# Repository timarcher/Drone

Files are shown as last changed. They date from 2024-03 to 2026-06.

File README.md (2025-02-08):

# Hexacopter Build Project
Welcome to the Hexacopter Build Project! Follow along as I embark on a journey to create a powerful 1300mm hexacopter from scratch. With a focus on scalability and payload capacity, I'm integrating top-tier components like a carbon fiber frame from RJX Hobby, Hobbywing XRotor X6 motors and a 12s smart battery, alongside exploring the Cube Pilot ecosystem for advanced flight control. I’ll also incorporate a companion computer and some cool cameras and imaging devices to explore things like photogrammetry and thermal imaging. From frame assembly to flight tuning, join me as I document every step of this exciting build, sharing my insights, code, and comprehensive parts list along the way. Let's push the boundaries of drone technology together!

For details [click here to access the wiki and documentation home folder.](./wiki/Drone-Wiki.md)

# Pictures
Hexacopter Pic 1

Hexacopter Pic 2

Hexacopter Pic 3

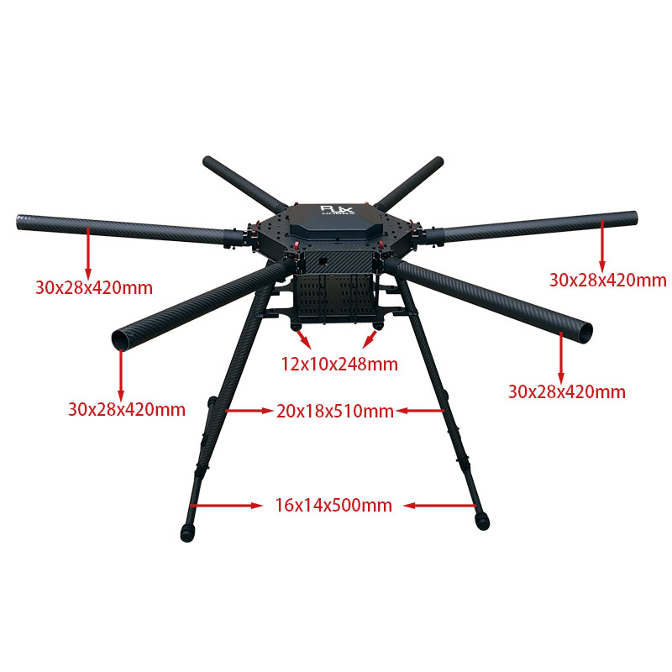
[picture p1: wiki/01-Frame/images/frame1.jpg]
Frame


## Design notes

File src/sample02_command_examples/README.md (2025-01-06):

This directory contains a script showing how to use mavlink to connect to a HereLink and send instructions to the flight controller.
It will attempt to:
- Arm the drone.
- Takeoff to a height of 3 meters.
- Read telemetry for 10 seconds and print to the screen.
- Land the drone.

To setup this script, you must do the following:
1. Make a directory to hold the scripts.
```sh
mkdir ~/drone_scripts
cd ~/drone_scripts
```
1. Copy the files to your linux machine into the diorectry ~/drone_scripts: requirements.txt and log_downloader.py
2. Setup your Python environment.
```sh
sudo apt update
sudo apt install python3-pip

python3 -m venv drone_scripts_env
source drone_scripts_env/bin/activate
pip3 install -r requirements.txt
```
3. Copy the script to your linux machine and execute it:
```sh
python3 sample02_command_examples.py
```

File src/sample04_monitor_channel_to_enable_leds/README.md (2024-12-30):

This directory contains a script to turn on and off the neopixel LEDs through RC Channel 6.
When that channel goes high, the LED scanning pattern will be enabled. When low, it will be turned off.

To setup this script, you must do the following:
1. Make a directory to hold the scripts.
```sh
mkdir ~/drone_scripts
cd ~/drone_scripts
```
2. Copy the files to your linux machine into the diorectry ~/drone_scripts: requirements.txt and monitor_channel_to_enable_leds.py
3. Setup your Python environment.
```sh
sudo apt update
sudo apt install python3-pip

python3 -m venv drone_scripts_env
source drone_scripts_env/bin/activate
pip3 install -r requirements.txt
```
4. Determine the absolute path of the Python interpreter in your environment: 
```sh
which python3
```
5. Create a Systemd Service File to auto start the script:
```sh
sudo vi /etc/systemd/system/led_monitor.service
```

Add the following content, replacing placeholders with actual paths:
```sh
[Unit]
Description=Monitor MAVLink channel and control LED strip
After=network-online.target
Wants=network-online.target

[Service]
Type=simple
User=ubuntu
WorkingDirectory=/home/ubuntu/drone_scripts
#ExecStartPre=/bin/sleep 60
ExecStart=/home/ubuntu/drone_scripts/drone_scripts_env/bin/python3 /home/ubuntu/drone_scripts/monitor_channel_to_enable_leds.py
#Restart=on-failure
Restart=always
TimeoutStartSec=120
Environment="PATH=/home/ubuntu/drone_scripts/drone_scripts_env/bin/python3:/usr/bin:/bin"
StandardOutput=journal
StandardError=journal

[Install]
WantedBy=multi-user.target
```

6. Reload Systemd and Enable the Service
```sh
sudo systemctl daemon-reload
sudo systemctl enable led_monitor.service
```

7. To test the service immediately, run:
```sh
sudo systemctl start led_monitor.service
```

8. Check its status to ensure it’s running:
```sh
sudo systemctl status led_monitor.service
```

9. Reboot and ensure the service is running then after the reboot:
```sh
sudo reboot
sudo systemctl status led_monitor.service
```

10. To debug issues, check the logs:
```sh
journalctl -u led_monitor.service -f
```

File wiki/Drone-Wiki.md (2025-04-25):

Welcome to the Hexacopter Build Project! Follow along as I embark on a journey to create a powerful 1300mm hexacopter from scratch. With a focus on scalability and payload capacity, I'm integrating top-tier components like a carbon fiber frame from RJX Hobby, Hobbywing XRotor X6 motors and a 12s smart battery, alongside exploring the Cube Pilot ecosystem for advanced flight control. I’ll also incorporate a companion computer and some cool cameras and imaging devices to explore things like photogrammetry and thermal imaging. From frame assembly to flight tuning, join me as I document every step of this exciting build, sharing my insights, code, and comprehensive parts list along the way. Let's push the boundaries of drone technology together!

# YouTube Play List
All of the YouTube videos linked in this wiki are organized into a [single playlist](https://www.youtube.com/playlist?list=PLT3XAJfSsN4FFodHkPWbuXHesVJ0ILG6v) you can watch as well. Follow each part of the video playlist in order.

# Preparation
- [Prep Work](Preparation/Preparation.md) - Prior to building and flying your drone, complete this prep work around knowledge, safety, and compliance.

# Bill of Materials
- [Overall BOM](00-Bill-of-Materials/Bill-of-Materials.md) - This page contains the overall bill of materials/component list that was used to construct the drone.

# Step by Step Build Process
Use the list below to follow my build journey step by step.
1. [Frame](01-Frame/Frame.md)
1. [Electronics](02-Electronics-Inventory/Electronics-Inventory.md)
1. [Herelink Unboxing and Configfuration](03-Herelink-Initial-Config/Herelink-Initial-Config.md)
1. [Cube Orange Plus and Kore Carrier Board Unboxing and Configfuration](04-Cube-Orange-Plus-and-Kore-Carrier-Board-Initial-Setup/Cube-Orange-Plus-and-Kore-Carrier-Board-Initial-Setup.md)
1. [Here 4 GPS and Base](05-Here-4-GPS-and-Base/Here-4-GPS-and-Base.md)
1. [Motors](06-Motors/Motors.md)
1. [Onboard OLED Display](07-OLED-Display/OLED-Display.md)
1. [Cube ID Remote ID](08-Cube-ID-Remote-ID/Cube-ID-Remote-ID.md)
1. [Here Flow](09-Here-Flow/Here-Flow.md)
1. [Onboard Computer and Ethernet](10-Onboard-Computer-and-Ethernet/Onboard-Computer-and-Ethernet.md)
1. [TFMini-S Lidar](11-TFMini-S-Lidar/TFMini-S-Lidar.md)
1. [Tattu Smart Battery](12-Tattu-Smart-Battery/Tattu-Smart-Battery.md)
1. [Electronics Installation](13-Electronics-Installation/Electronics-Installation.md)
1. [Navigation Lights](14-Navigation-Lights/Navigation-Lights.md)
1. [Peripheral Updates](15-Peripheral-Updates/Peripheral-Updates.md)
1. [Gimbal and Camera](16-Gimbal-and-Camera/Gimbal-and-Camera.md)
1. [Obstacle Avoidance LiDAR](17-Obstacle-Avoidance-LiDAR/Obstacle-Avoidance-LiDAR.md)
1. [Scanning Lights / Cylon Pattern](18-Scanning-Lights/Scanning-Lights.md)

<!--1. [Methodic Configuration](XX-Methodic-Configuration/Methodic-Configuration.md)-->
<!--1. [ROS Integration](XX-ROS-Integration/ROS-Integration.md)-->

Future steps are coming soon!

# Drone Weight
The weight of this drone is as follows:
- 21.64 lb without battery or payload (just frame, motors, electronics, etc).
- 31.30 lb with battery (The battery is 9.66 lb).
- 27.15 lb with payload and no battery (5.51 lb payload). The payload is the Gremsy T7 Gimbal, Sony A6500 Camera, and supporting electronics.
- 36.85 lb with battery and payload

# Flight Checklist
- [Flight Checklist](Flight-Checklist/Flight-Checklist.md) - This page contains a simple checklist of items to work through before flying.

# Full ArduPilot Configuration Summary
- [ArduPilot Configuration](ArduPilot-Config/ArduPilot-Config.md) - This page contains a consolidated list of the all of the configuration done in ArduPilot throughout the videos.
- However, I would recommend you use the [ArduPilot Methodic Configurator](https://ardupilot.github.io/MethodicConfigurator/TUNING_GUIDE_ArduCopter) with [these config files](../ardupilot-methodic-configurator/Hexacopter/) that I have created. This is how I setup and tuned the drone in its final stages.

# ArduPilot Tools
- [DroneCAN GUI Tool](https://dronecan.github.io/GUI_Tool/Overview/) - a coss-platform free open source application for DroneCAN bus management and diagnostics.
- [Mission Planner](https://ardupilot.org/planner/docs/mission-planner-installation.html) - A GCS allows users to set-up, configure, test, and tune the vehicle. 
- [MavProxy](https://ardupilot.org/mavproxy/) - A UAV ground station software package for MAVLink based systems.

# Flight Training
- [RealFlight Simulator](https://www.realflight.com/) - Awesome flight simulator software you can use to learn to safely fly on your computer.
- [How to Fly a Drone A Beginner's Guide to Multirotor Systems & Flight Proficiency by UAV Coach](https://uavcoach.com/how-to-fly-a-quadcopter-guide/) - Need to learn some of the basics of flying? Start with UAV Coach. The information and videos here will give you basic exercises you can practice to improve your flying skills.

# Other Resources
- [eCalc](https://ecalc.ch/) - Services to simulate, calculate, evaluate and design electric brushless motor drives for RC pilots of airplane, multi rotor, UAV, helicopter and EDF jets.
- [How to methodically configure and tune any ArduCopter Blog Post](https://discuss.ardupilot.org/t/how-to-methodically-configure-and-tune-any-arducopter/110842)
- [Measuring Vibration ArduPilot Article](https://ardupilot.org/copter/docs/common-measuring-vibration.html) - These instructions explain how to measure the vibration levels. If you find they are out-of-tolerance then follow the advice found on the ArduPilot Vibration Damping page.
- [Log Analysis in Mission Planner](https://youtu.be/xhBd9KSAfzg?si=X1SPhqCtfS4Ki4Zp) - A video from Dan Benson offering a complete discussion of log analysis in mission planner. He uses a crash to illustrate how to use the log analysis.

# Pictures
Hexacopter Pic 1

Hexacopter Pic 2

Hexacopter Pic 3

Frame

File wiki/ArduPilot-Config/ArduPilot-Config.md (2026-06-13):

This page contains a consolidated list of the all of the configuration done in ArduPilot throughout the videos. 
Use this to easily setup a new flight controllers.

# Custom Firmware
You will need to build your own custom firmware from [custom.ardupilot.org](http://custom.ardupilot.org/) in order to enable the DID_* parameters for Open Drone ID.
- Press "Add a build"
- For vehicle select Copter
- For branch Select the latest stable branch (i.e., Copter 4.5 stable)
- For board select CubeOrangePlus
- Under the Ident category, check the box for OpenDroneID (Remote ID)
- Press the "Generate Build" button
- Download the generated arducopter.apj file.
- In Mission Planner, go to Setup->Install Firmware
- Press "Load Custom Firmware"
- Select the apj file you downloaded and flash it to the board

# All Firmware and Software Versions
This section lists all the firmware and software versions I am using in this build:
|Component|Version|Link|
|---|---|---|
|ArduCopter|4.6.3|https://custom.ardupilot.org/|
|Gremsy T7 Gimbal|7.8.7|https://github.com/Gremsy/T7-Firmware/releases|
|AirPixel Air Commander Entire R3|2.026|https://airpixel.cz/docs/firmware-update/|
|HereLink QGroundControl|5.0.8-1|https://github.com/CubePilot/qgroundcontrol-herelink/releases|
|MavCam HL|2.24|https://airpixel.cz/docs/herelink-camera-control/|
|Gremsy gTuneDesktop|1.4.9.7|https://github.com/Gremsy/gTuneDesktop/releases|
|AP_Periph MatekL431-Rangefinder|Jun 3 2025|https://firmware.ardupilot.org/AP_Periph/stable/MatekL431-Rangefinder/|
|AP_Periph MatekL431-Proximity|Jun 3 2025|https://firmware.ardupilot.org/AP_Periph/stable/MatekL431-Proximity/|
|Mission Planner|Latest Beta Release|https://ardupilot.org/planner/docs/mission-planner-installation.html|
|ArduPilot Methodic Configurator|Latest Release|https://github.com/ArduPilot/MethodicConfigurator/releases|
|Here4 GPS Firmware|1.15.7|https://github.com/CubePilot/GNSSPeriph-release/releases|
|Tattu TA3200 LiPo Charger Firmware|5/28/2025, v1.4.2|https://www.grepow.com/downloads.html|
|LightWare Studio|1.21.11|https://lightwarelidar.com/resources-software/|
|LightWare SF45 Firmware|External (Motor Controller) 1.3.0 / Internal (LiDAR) 1.1.2|Use LightWare Studio to get latest|

# Initial Setup
After flashing firmware for the first time, use Mission Planner to configure several items:
- Go to Setup tab.
- Expand the Mandatory Hardware menu item.
  - On Frame Type menu item:
    - Select the Hexacopter X pattern.
  - On Initial Tune Parameters menu item:
    - Airscrew Inch Size: 24
    - Battery Cellcount: 12 (or 6 when testing with a 6s battery)
    - Battery cell fully discharged voltage: 3.3
    - Check the option to "Add suggested settings for 4.0 and up (Battery failsafe and Fence)".
    - Press the "Calculate Initial Parameters" button, and then the "Write to FC" button on the popup window.
  - On Accel Calibration menu item:
    - Press Calibrate Accel (use this for when you can manipulate the drone orientation)
    - Press Calibrate Level
    - Press Simple Accel Cal (use this in lieu of Calibrate Accel for large drone or simple bench testing)
    - Docs on accelerometer calibration [can be found here](https://ardupilot.org/copter/docs/common-accelerometer-calibration.html).    
  - On Compass menu item:
    - Swap compasses later to use the external one higher priority than the one on cube once the GPS is installed.
    - Press start on the Onboard Mag Calibration, calibrate, and reboot. Docs on compass calibration [can be found here](https://ardupilot.org/copter/docs/common-compass-calibration-in-mission-planner.html).
  - On Radio Calibration menu item:
    - Prior to calibrating, I had to reverse the joystick outputs in the Herelink controller for the Y (throttle rc2). Otherwise the values were reversed.
    - Press the Calibrate Radio button. Move joysticks and input buttons to their limits. Then press the Click when Done button.
    - Docs on radio calibration [can be found here](https://ardupilot.org/copter/docs/common-radio-control-calibration.html).
    - Be sure to test the controls in Mission Planner. Move the transmitter’s roll, pitch, throttle and yaw sticks and ensure the green bars move in the correct direction:
      - For roll, throttle and yaw channels, the green bars should move in the same direction as the transmitter’s physical sticks.
      - For pitch, the green bar should move in the opposite direction to the transmitter’s physical stick.
      - If one of the green bars moves in the incorrect direction reverse the channel in the transmitter itself. If it is not possible to reverse the channel in the transmitter you may reverse the channel in ArduPilot by checking the “Reversed” checkbox (Plane and Rover only). If the checkbox is not visible it is possible to reverse the channel by directly changing the RCx_REVERSED parameter (where “x” is the input channel from 1 to 4).

# Parameter Settings
To set these parameters in mission planner, navigate to the Config tab, and then the Parameter List menu option.
Note: If you are using a fresh installation of mission planner you will have to enable this page by setting Config->Planner->Layout to “Advanced”

## Parameters - Herelink Telemetry
I changed the default baud rate from 57600 to 115200.
You must also change the baud rate on the air unit. To do this, open the herelink settings, go to Airunit, select 115200 for the baudrate and click Reset Baud.

|Parameter Name|Value|Description|
|---|---|---|
|SERIAL1_BAUD|115|The MAVLink over Herelink telemetry, changed from default of 57600 to 115200.|

## Parameters - Kore carrier board voltage and current sensors
The default params recommended for battery monitoring are on the Kore carrier board page.
However, with the defaults I was getting negative current readings. Per this post I set the BATT_AMP_OFFSET to 0.37. There is also a recommendation to set BATT_AMP_PERVOLT to 67 but I did not do that.
https://discuss.cubepilot.org/t/negative-current-reading-on-kore-carrier-board/2299/11
You do not need to set these if you are going to use the settings below for the Tattu Smart Battery. That battery has a BMS from which ArduPilot can get it's status through DroneCAN.

|Parameter Name|Value|Description|
|---|---|---|
|BATT_MONITOR|4|Set this first, and then write the params so the other ones below show. Must reboot the board after changing. 4 = Analog voltage and current.|
|BATT_AMP_OFFSET|0.37|Kore docs recommend 0.45 but this caused negative current readings on my board.|
|BATT_AMP_PERVLT|50||
|BATT_ARM_VOLT|44.3|Minimum battery voltage required to arm the aircraft.|
|BATT_CAPACITY|15800|The Tattu 12s battery has 16000 mah.|
|BATT_CRT_VOLT|42|Battery voltage that triggers a critical battery failsafe.|
|BATT_CURR_PIN|15|Kore docs recommend 3, but I had to set to 15 to work with Cube Orange Plus.|
|BATT_FS_CRT_ACT|1|Action to perform if the critical battery failsafe is hit. 1 = Land|
|BATT_FS_LOW_ACT|2|Action to perform if the low battery failsafe is hit. 2 = RTL|
|BATT_LOW_VOLT|43.2|Battery voltage that triggers a low battery failsafe.|
|BATT_SERIAL_NUM|-1|Leave at -1.|
|BATT_VOLT_MULT|15.2||
|BATT_VOLT_PIN|14|Kore docs recommend 2, but I had to set to 14 to work with Cube Orange Plus.|

> If you are using the Tattu Smart Battery outlined below, you should skip setting these BATT_* parameters for the Kore Carrier Board. If you wish, you may set the Tattu smart battery settings as described below under BATT_, and then set these values under BATT2_ instead of BATT_ to have a secondary battery monitor using the circuity on the Kore carrier board. If you do that, I recommend you set BATT2_MONITOR to a value of 3, monitoring the analog voltage only. The remaining capacity is more accurately measured through the smart battery, and so also trying to measure current through the Kore carrier board will show a remaining capacity on the 2nd battery monitor that is wrong because it resets between flight controller reboots.

## Parameters - Enable DroneCAN (Needed for Basically everything below)
|Parameter Name|Value|Description|
|---|---|---|
|CAN_P1_DRIVER|1|1st Driver.|
|CAN_P2_DRIVER|2|2nd Driver.|
|CAN_D1_PROTOCOL|1|DroneCAN.|
|CAN_D2_PROTOCOL|1|DroneCAN.|

## Parameters - Here4 GPS
|Parameter Name|Value|Description|
|---|---|---|
|BRD_SAFETY_DEFLT|0|There is no safety switch on the Here4 GPS so we disable it. (BRD_SAFETYENABLE in older firmware versions)|
|GPS1_TYPE|9|GPS type of 1st GPS.|
|NTF_LED_TYPES|231|Controls what types of LEDs will be enabled.|
|GPS_AUTO_CONFIG|2|Needed to enable RTK autocorrect, set to enable for DroneCAN as well.|

If using multiple GPS', as in my drone, also need to set additional params. In my drone, GPS1 (Node 119) is the GPS on the right middle arm of the vehicle, and GPS2 (Node 118) is the GPS on the left middle arm of the vehicle.
|Parameter Name|Value|Description|
|---|---|---|
|GPS1_CAN_OVRIDE|119|Node ID for the 1st GPS. Set appropriately for your vehicle as the Node IDs might be different.|
|GPS2_TYPE|9|GPS type of 2nd GPS.|
|GPS2_CAN_OVRIDE|118|Node ID for the 1st GPS. Set appropriately for your vehicle as the Node IDs might be different.|
|GPS_AUTO_SWITCH|1|Set to Use Best.|

Additionally, you may wish to set the offsets of the sensors relative to the center of your Cube Orange.  Customize the value by measuring the offset from the center of your Cube Orange to the middle of the sensor.
|Parameter Name|Value|Description|
|---|---|---|
|GPS1_POS_X|0.07|X position of the second GPS antenna in body frame. Positive X is forward of the origin. Units in meters.|
|GPS1_POS_Y|0.2413|Y position of the second GPS antenna in body frame. Positive Y is to the right of the origin. Units in meters.|
|GPS1_POS_Z|0.01|Z position of the second GPS antenna in body frame. Positive Z is down from the origin. Units in meters.|
|GPS1_GNSS_MODE|5|Constellations to be used. 0=Set to allow all. 65=GPS and Galileo|
|GPS2_POS_X|0.07|X position of the first GPS antenna in body frame. Positive X is forward of the origin. Units in meters.|
|GPS2_POS_Y|-0.2413|Y position of the first GPS antenna in body frame. Positive Y is to the right of the origin. Units in meters.|
|GPS2_POS_Z|0.01|Z position of the first GPS antenna in body frame. Positive Z is down from the origin. Units in meters.|
|GPS2_GNSS_MODE|5|Constellations to be used. 0=Set to allow all. 65=GPS and Galileo|

New RTK can be used to estimate yaw, in addition to providing position information. This removes the need for a compass which may suffer from magnetic interference from the ground or the vehicle’s motors and ESCs. Set the following to use this as well:
|Parameter Name|Value|Description|
|---|---|---|
|EK3_SRC1_YAW|3|GPS with compass fallback|
|GPS1_TYPE|22|DroneCAN moving baseline base|
|GPS2_TYPE|23|DroneCAN moving baseline rover|
|GPS_AUTO_CONFIG|2|Autoconfig DroneCAN|
|GPS_AUTO_SWITCH|1|Use Best|

> Be sure you set the GPS1_POS_X/Y/Z and GPS2_POS_X/Y/Z parameters for the GPS antennas (see Sensor Position Offset are here) as described above. You must establish the relative positions of each GPS location on the vehicle with respect the vehicle’s motion.

<!--
|XXX|XXX|XXX|
-->

## Parameters - Onboard OLED Display
|Parameter Name|Value|Description|
|---|---|---|
|NTF_DISPLAY_TYPE|1|SSD1306 OLED Connected to I2C.|

## Parameters - Motors
|Parameter Name|Value|Description|
|---|---|---|
|CAN_D1_UC_ESC_BM|63|Bitmask that determines which autopilot servo/motor output signals are sent to the DroneCAN ESCs. 63 = ESC 1 through 6.|
|CAN_D1_UC_OPTION|128|Set options for the DroneCAN driver for Hobbywing ESC.|

## Parameters - Cube ID
Be sure to build and load the custom firmware as described above. Otherwise, you will not see any of the DID_* parameters.
|Parameter Name|Value|Description|
|---|---|---|
|DID_ENABLE|1|Enable Open Drone ID|
|DID_CANDRIVER|1|DroneCAN driver index, 0 to disable DroneCAN.|
|DID_OPTIONS|6|6 sets AllowNonGPSPosition and LockUASIDOnFirstBasicIDRx. First setup the above two params, setup your Drone ID info in mission planner, verify it shows in Drone Scanner, and then set this bit. After your DID_UAS_ID is persisted, the LockUASIDOnFirstBasicIDRx will be unchecked in the params and this value set back to a 2.|

You can optionally set the DID_OPTIONS bitmask value as well for EnforceArming, AllowNonGPSPosition, and LockUASIDOnFirstBasicIDRx.
- EnforceArming = set to enforce arming checks
- AllowNonGPSPosition = allow drone to be armed without a GPS position. If you want to be able to arm without the operator location set this bit. Useful when testing flight controller indoors and not actually flying. You'll hear your Herelink repeat the error "ODID Lost Operator Location" which can get annoying after awhile.
- LockUASIDOnFirstBasicIDRx = To meet FAA requirements for manufacturers, a persistent ID needs to be recorded in Flight system. To achieve this with CubeID + Ardupilot setup. Ardupilot's persistent storage feature is used. After the setting, the first reception of Basic ID containing Drone ID and other details (from Mission Planner or any other GCS) will be persistently recorded. Please note that once set the persistent parameters can't be rolled back. Once the UAS ID is persisted, this will be unchecked and the values stored in the persistent.parm file on the flight controller. It will persist DID_UAS_ID, DID_UAS_ID_TYPE, and DID_UA_TYPE.

## Parameters - Here Flow
|Parameter Name|Value|Description|
|---|---|---|
|RNGFND1_TYPE|24|Type of connected rangefinder. Reboot flight controller after setting this for rest of the params to show.|
|RNGFND1_MIN_CM|10|Minimum distance in centimeters that rangefinder can reliably read.|
|RNGFND1_MAX_CM|200|Maximum distance in centimeters that rangefinder can reliably read.|
|RNGFND1_GNDCLEAR|29|Optional - This parameter sets  the expected range measurement(in cm) that the range finder should return when the vehicle is on the ground.|
|FLOW_TYPE|6|Enable optical flow camera.|

Additionally, you may wish to set the offsets of the sensors relative to the center of your Cube Orange.  Customize the value by measuring the offset from the center of your Cube Orange to the middle of the sensor.
|Parameter Name|Value|Description|
|---|---|---|
|FLOW_POS_X|-0.140|X position of the optical flow sensor focal point in body frame. Positive X is forward of the origin. Units in meters.|
|FLOW_POS_Y|-0.075|Y position of the optical flow sensor focal point in body frame. Positive Y is to the right of the origin. Units in meters.|
|FLOW_POS_Z|0.206|Z position of the optical flow sensor focal point in body frame. Positive Z is down from the origin. Units in meters.|

## Parameters - TFMini-S LiDAR
|Parameter Name|Value|Description|
|---|---|---|
|SERIAL4_PROTOCOL|9|What protocol Serial4 port should be used for. Change from -1 (GPS) to 9 (Lidar)|
|SERIAL4_BAUD|115|The baud rate used for Serial4. 115200 baud.|
|RNGFND2_TYPE|20|Type of connected rangefinder. 20=Benewake-Serial. Reboot flight controller after setting this for rest of the params to show.|
|RNGFND2_MIN_CM|10|Minimum distance in centimeters that rangefinder can reliably read. 10 for TFminiPlus|
|RNGFND2_MAX_CM|600|This is the distance in centimeters that the rangefinder can reliably read. 600 for outdoors.|
|RNGFND2_GNDCLEAR|29|Optional - This parameter sets  the expected range measurement(in cm) that the range finder should return when the vehicle is on the ground.|

If using the Matek AP_PERIPH CAN Node L431 Board to convert your TFMini-S to a DroneCAN device, then set these instead:
|Parameter Name|Value|Description|
|---|---|---|
|RNGFND2_TYPE|24|Type of connected rangefinder. 24=DroneCAN. Reboot flight controller after setting this for rest of the params to show.|
|RNGFND2_MIN_CM|10|Minimum distance in centimeters that rangefinder can reliably read. 10 for TFminiPlus|
|RNGFND2_MAX_CM|600|This is the distance in centimeters that the rangefinder can reliably read. 600 for outdoors.|
|RNGFND2_GNDCLEAR|45|Optional - This parameter sets  the expected range measurement(in cm) that the range finder should return when the vehicle is on the ground.|

Additionally, you may wish to set the offsets of the sensors relative to the center of your Cube Orange.  Customize the value by measuring the offset from the center of your Cube Orange to the middle of the sensor.
|Parameter Name|Value|Description|
|---|---|---|
|RNGFND1_POS_X|-0.160|X position of the rangefinder in body frame. Positive X is forward of the origin. Units in meters.|
|RNGFND1_POS_Y|0|Y position of the rangefinder in body frame. Positive Y is to the right of the origin. Units in meters.|
|RNGFND1_POS_Z|0.211|Z position of the rangefinder in body frame. Positive Z is down from the origin. Units in meters.|

## Parameters - Tattu 12s 16000mAh Smart Battery
These are the settings I used for the Tattu Plus 1.0 Compact Version 16000mAh 44.4V 15C 12S1P Lipo Smart Battery Pack With AS150U Plug.
|Parameter Name|Value|Description|
|---|---|---|
|BATT_MONITOR|8|DroneCAN|
|BATT_AMP_OFFSET|0|This may not show up once you set BATT_MONITOR to 8. Thats OK.|
|BATT_AMP_PERVLT|1|This may not show up once you set BATT_MONITOR to 8. Thats OK.|
|BATT_ARM_VOLT|44.3|Minimum battery voltage required to arm the aircraft.|
|BATT_CAPACITY|15800|The Tattu 12s battery has 16000 mah.|
|BATT_CRT_VOLT|42|Battery voltage that triggers a critical battery failsafe.|
|BATT_CURR_MULT|-1|Multiplier applied to all current related reports. Needed otherwise you get negative current readings from the Tattu battery.|
|BATT_FS_CRT_ACT|1|Action to perform if the critical battery failsafe is hit. 1 = Land|
|BATT_FS_LOW_ACT|2|Action to perform if the low battery failsafe is hit. 2 = RTL|
|BATT_LOW_VOLT|43.2|Battery voltage that triggers a low battery failsafe.|
|BATT_SERIAL_NUM|-1|Leave at -1 unless you have multiple DroneCAN batteries in the drone.|
|MOT_BAT_VOLT_MAX|50.4|Battery voltage compensation maximum voltage. Set to 4.2 * cell count.|
|MOT_BAT_VOLT_MIN|39.6|Battery voltage minimum compensation voltage. Set to 3.3 * cell count.|

## Parameters - Flytron STROBON Cree V2 Lights
|Parameter Name|Value|Description|
|---|---|---|
|SERVO9_FUNCTION|56|Configure for RC Pass thru. 56 = RCIN6 which means RC channel 6 gets output to SERVO9.|

> On the Kore carrier board SERVO9 - SERVO15 are mapped to the 6 auxiliary outputs.
> For testing, on the Herelink controller, go to the settings and map a button to a channel. In my testing I mapped a short press of the D button to RC channel 6, and it toggles between a value of 1000 and 2000 when pressed. And then in Ardupilot, I set SERVO9_FUNCTION to 56, which means to pass RC channel 6 (RCIN6) through to SERVO9. SERVO9 corresponds to the first auxiliary output on the Kore carrier board.

## Parameters - Flight Modes
I have my flight modes configured as follows. This requires some config in ArduPilot as well as the HereLink controller. You can also set these up in Mission Planner on the Setup->Flight Modes screen.

|Parameter Name|Value|Description|
|---|---|---|
|FLTMODE_CH|5|RC Channel to use for flight mode control. Default is 5.|
|FLTMODE1|5|Flight mode when pwm of Flightmode channel(FLTMODE_CH) is <= 1230. Set to Loiter.|
|FLTMODE2|15|Flight mode when pwm of Flightmode channel(FLTMODE_CH) is >1230, <= 1360. Set to AutoTune.|
|FLTMODE3|2|Flight mode when pwm of Flightmode channel(FLTMODE_CH) is >1360, <= 1490. Set to AltHold.|
|FLTMODE4|3|Flight mode when pwm of Flightmode channel(FLTMODE_CH) is >1490, <= 1620. Set to Auto.|
|FLTMODE5|6|Flight mode when pwm of Flightmode channel(FLTMODE_CH) is >1620, <= 1749. Set to RTL.|
|FLTMODE6|9|Flight mode when pwm of Flightmode channel(FLTMODE_CH) is >=1750. Set to Land.|

On the HereLink controller I configured the A, B, and Home buttons to control my flight modes using the following steps:
- On the HereLink controller in the settings area, go to the buttons tab.
-  Flight Mode 1 - Loiter - PWM 0-1230 - Mapped to button A short press, active value 1100, mark as default button
-  Flight Mode 2 - AutoTune - PWM 1231-1360 - Mapped to button A long press, active value 1300
-  Flight Mode 3 - AltHold - PWM 1361-1490 - Mapped to button B short press, active value 1425
-  Flight Mode 4 - Stabilize - PWM 1491-1620 - Mapped to button B long press, active value 1550
-  Flight Mode 5 - Smart_RTL - PWM 1621-1749 - Mapped to button home short press, active value 1675
-  Flight Mode 6 - Land - PWM 1750+ - Mapped to button home long press, active value 1800

## Parameters - RC Failsafe
- In Mission Planner go to the Setup -> FailSafe tab. Configure the radio failsafe to Enabled always RTL, and an FS PWM of 975
- [Failsafe documentation is available here](https://ardupilot.org/copter/docs/failsafe-landing-page.html).

|Parameter Name|Value|Description|
|---|---|---|
|RC_FS_TIMEOUT|1|RC failsafe will trigger this many seconds after loss of RC.|
|FS_THR_ENABLE|1|The throttle failsafe allows you to configure a software failsafe activated by a setting on the throttle input channel. Set to Enabled, always RTL. If the GPS position is not usable, the copter will change to Land Mode instead.|
|FS_THR_VALUE|975|The PWM level in microseconds on channel 3 below which throttle failsafe triggers.|

## Parameters - GeoFence
A fence is a virtual boundary set in the flight control system that restricts the area within which an unmanned aerial vehicle (UAV) can operate, helping to ensure it stays within a predefined safe zone and enhancing flight safety. If the UAV attempts to cross this boundary, the system can trigger predefined actions like returning to launch or landing. Upon Fence breach, selectable actions are taken.

- In Mission Planner go to the Config->GeoFence tab. Configure the GeoFence settings to control the distance your drone is allowed to go from it's launch point.

|Parameter Name|Value|Description|
|---|---|---|
|FENCE_ACTION|4|4 = Brake or Land. Set to 0 for report only.|
|FENCE_ALT_MAX|30|Maximum altitude allowed before geofence triggers. Value is in meters. I set to 30 when initially testing drone.|
|FENCE_ALT_MIN|-10|Minimum altitude allowed before geofence triggers. Value is in meters.|
|FENCE_AUTOENABLE|0|Auto-enable of fences. Set to Disabled.|
|FENCE_ENABLE|1|Allows you to enable (1) or disable (0) the fence functionality.|
|FENCE_MARGIN|3|Distance that autopilot's should maintain from the fence to avoid a breach. Value is in meters.|
|FENCE_RADIUS|100|Circle fence radius which when breached will cause an RTL. Value is in meters.|
|FENCE_TYPE|7|Bitmask. Set to Max Altitude, Circle Centered on Home, and Inclusion/Exclusion Circles+Polygons|

## Parameters - Additonal RC Channel Options
- In Mission Planner you can also go to the Config->User Params tab and map actions to other channels as desired. For example you could map channel 7 to fence enable/disable. This would be the same as setting RC7_OPTION to a value of 11. Other fun things, for example, you could map it to the lost copter sound.

|Parameter Name|Value|Description|
|---|---|---|
|RC7_OPTION|11|Function assigned to this RC channel. Set to Fence Enable.|

## Parameters - Waypoint Navigation
I have adjusted these parameters to be about half the default value to make my drone move more slowly during missions.

|Parameter Name|Value|Description|
|---|---|---|
|WPNAV_SPEED|500|Defines the speed in cm/s which the aircraft will attempt to maintain horizontally during a WP mission.|
|WPNAV_SPEED_UP|150|Defines the speed in cm/s which the aircraft will attempt to maintain while climbing during a WP mission.|
|WPNAV_SPEED_DN|100|Defines the speed in cm/s which the aircraft will attempt to maintain while descending during a WP mission.|
|WPNAV_ACCEL|125|Defines the horizontal acceleration in cm/s/s used during missions.|
|WPNAV_ACCEL_Z|75|Defines the vertical acceleration in cm/s/s used during missions.|

## Parameters - Gremsy T7 Gimbal
|Parameter Name|Value|Description|
|---|---|---|
|CAM1_TYPE|5|Camera shutter (trigger) type of MAVLink.|
|MNT1_DEFLT_MODE|2|Mount default operating mode on startup and after control is returned from autopilot. 2 is MavLink targeting. 3 is RC Targeting.|
|MNT1_OPTIONS|2|Return to neutral position on RC failsafe.|
|MNT1_PITCH_MAX|20|Mount Pitch angle maximum.|
|MNT1_PITCH_MIN|-90|Mount Pitch angle minimum.|
|MNT1_RC_RATE|90|Pilot rate control's maximum rate. Deg/s.|
|MNT1_TYPE|6|For Gremsy. Reboot after changing this param.|
|MNT1_YAW_MAX|90|Mount Yaw angle maximum.|
|MNT1_YAW_MIN|-90|Mount Yaw angle minimum.|
|SERIAL2_BAUD|921|Communication at 921600 bps.|
|SERIAL2_PROTOCOL|2|Mavlink2|
|SERIAL2_OPTIONS|0|Default|

## Parameters - LightWare SF45/B Proximity Sensor
If using the Matek AP_PERIPH CAN Node L431 Board to convert your LightWare sensor to a DroneCAN device, then set these parameters is Mission Planner on the Cube:
|Parameter Name|Value|Description|
|---|---|---|
|PRX1_TYPE|14|Type of connected proximity sensor. 14=DroneCAN. Reboot flight controller after setting this for rest of the params to show.|
|PRX1_MIN|0.2|Minimum expected range for Proximity Sensor. Setting this to 0 will set value to manufacturer reported range.|
|PRX1_MAX|40|Maximum expected range for Proximity Sensor. Setting this to 0 will set value to manufacturer reported range.|
|AVOID_ALT_MIN|1.5|Minimum altitude (in meters) above which proximity based avoidance will start working. This requires a valid downward facing rangefinder reading to work. Set zero to disable.|
|AVOID_BEHAVE|1|Avoidance behaviour of stop.|
|AVOID_DIST_MAX|5|Distance from object at which obstacle avoidance will begin in non-GPS modes.|
|AVOID_ENABLE|3|Bitmask for Fence and Proximity.|
|AVOID_MARGIN|3|Vehicle will attempt to stay at least this distance (in meters) from objects while in GPS modes.|

And set these parameters on the Matek L431 Device:
|Parameter Name|Value|Description|
|---|---|---|
|PRX_BAUDRATE|115200|Baudrate to communicate with the sensor at.|
|PRX_PORT|2|Serial Port on the Matek L431.|
|PRX1_TYPE|8|LightWare SF45/B.|
|PRX1_ORIENT|0|Normal orientation (i.e., not upside down).|
|PRX1_YAW_CORR|0|Proximity sensor yaw correction. (its facing forward)|

## Parameters - Board Boot Delay
|Parameter Name|Value|Description|
|---|---|---|
|BRD_BOOT_DELAY|3000|This adds a delay in milliseconds to boot to ensure peripherals initialise fully. Value in milliseconds.|

# Factory Reset the Parameters
If, for some reason, you ever want to reset all of the parameters to their defaults you can follow any of the methods [listed here](https://ardupilot.org/copter/docs/common-parameter-reset.html).

To reset all params to defaults in MavProxy, first install MavProxy and then open MavProxy and run these commands:
- link add COM6
- param show FORMAT_VERSION
- param set FORMAT_VERSION 0
- reboot

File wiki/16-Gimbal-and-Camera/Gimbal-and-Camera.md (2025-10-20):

This page contains details on setting up the Gremsy T7 Gimbal, a Sony a6500 Camera, and AirPixel Air Commander on the drone.

# YouTube Video
- [Hexacopter Drone Build Project – Part 16 Gimbal and Camera](https://youtu.be/ZaLEz2Q5GR8)

# Notes
- I replaced the stock 12mm payload carbon fiber tubes that came with the drone with longer 330mm ones from Amazon.
- I bought a longer 6-Pin JST-GH Twisted Pair - MRC0212 - 1000mm length cable from 3DR in order to make the serial connection from the gimbal to the Kore carrier board. Its a 6 pin connector and wire designed for I2C, but I removed 3 wires and swapped TX/RX on one end to make it work for the gimbal.
- The gimbal serial connection gets connected to the Telemetry 2 port on the Kore carrier board. See [this page for the wiring diagram](https://ardupilot.org/copter/docs/common-gremsy-pixyu-gimbal.html). We change this to a baud rate of 921,600 per the Air Commander documentation in ArudPilot by setting SERIAL2_BAUD = 921.
  - Set your ArduPilot parameters as defined under the section Parameters - Gremsy T7 Gimbal in the [ArduPilot Configuration](../ArduPilot-Config/ArduPilot-Config.md#) wiki page.
- Gremsy Gimbal Configuration
  - Ensure you load the latest firmware, 7.7.1 or later! Download from https://github.com/Gremsy/T7-Firmware/releases
    - NOTE: Gyro MUST be calibrated after upgrading completely.
      Open gTune --> SETTINGS --> GYRO --> CALIBRATE
      NOTE: Users should load the recommended gimbal parameters and perform an AUTO-TUNE process.
      Open gTune --> SETTINGS --> STIFFNESS --> AUTOTUNE
  - Tuning the stiffness: Increase the stiffness setting 5-10 points at a time until oscillation appears then reduce 5 points until oscillation subsides. Slowly increase this setting until you feel an oscillation in the tilt axis, then reduce the setting until the oscillation subsides.
    - I have my stiffness settings at: Tilt 25, Roll 45, Pan 45. Gyro Filter 2, and Output Filter 3
  - In the Gremsy GTuneDesktop app, change these options:
    - Settings -> Controls -> Mavlink - Set to enabled
      - Configure COM2 baudrate to 921600bps (used for connection to Cube)
      - Configure COM4 baudrate to 230400bps (used for Air Commander ENTIRE connection)
    - Settings -> Rotation - I set Tilt up to -20. I didnt want it to be able to tilt up a bunch.
    - Settings -> Follow - Change toggle swith to Pan. Set Speed to 30 so the gimbal yaw will follow the drone yaw faster.
    - Also go to the settings button in top left under mode, and unselect the "Reduce Drift by Drone" option, Pan Axis will be disabled.
- Sony A6500 Camera Configuration
  - Enable RemoteCtrl function in the Camera menu for the Air Commander IR light to be able to control the menu.
    - Camera Menu -> Setup (toolbox icon) -> Setup4 screen -> Scroll to the Remote Ctrl setting and make sure it’s set to On.
  - Turn the camera USB mode to the appropriate mode:
    - MASS STORAGE mode is used for geotagging. This mode prevents you from controlling the cameras ISO, Shutter Speed and Aperture. Use this for mapping type of work.
      - Camera Menu -> Setup (toolbox icon) -> Setup4 screen -> USB Connection. Set to Mass Storage and confirm OK.
    - PC REMOTE mode is prevents you from geotagging, but you can control the camera's ISO, Shutter Speed and Aperture. Use this mode for photo and video work.
      - Camera Menu -> Setup (toolbox icon) -> Setup4 screen -> USB Connection. Set to PC Remote and confirm OK.
      - You will also need the Air Commander Entire to not be in Direct Exif Geotagging mode for this to work. (Enable GeoTagging via MENU -> Logging mode-> Direct EXIF (or SD card))
    - If you want to have BOTH geotagging AND camera control, then you need to setup the camera in mass storage mode and configure [wifi for camera control on the Air Commander](https://airpixel.cz/docs/wifi-for-camera-control/). This connected on my A6500 Camera, but it did not work as advertised...Try at your will, but it may not work as you expect. EDIT 10/20/25 - I had to use USB mode instead of WiFi mode in order to be able to take both pictures and video. Video would not work when in WiFi mode.
      - To do this, in the camera enable wifi remote control: MENU → (Application) → [Application List] → [Smart Remote Embedded].
      - Then, login to the Entire admin control. 
        - Switch Entire to WiFi control mode. Manage Entire to connect the Camera WiFi hotspot:MENU -> WiFi connection
        - Select first empty slot
        - Click to New Scan and wait  until scan is not ready
        - From drop down list selelct camera WiFi hotspot
        - Write down password from the camera
        - Click to Connect
        - Entire will connect the camera. During camera connection, Entire will disable own hotspot, so you’ll be disconnected. During connection Entire blinks quickly Blue/Green.
        - Once connection is done, Entire will go Blue or Green, then you can connect back from your phone or PC.
        - You can also add the "Sony Imagine Edge" mobile app to your phone and connect to your camera.
  - Enable Info Display on the Camera HDMI Output
    - Camera Menu -> Setup (toolbox icon) -> Setup4 screen -> HDMI. Change Info Display to On.
  - Disable AutoReview
    - Camera Menu -> Camera Settings 2 -> Auto Review. Change to off.
  - Change Type of Image Captured
    - Camera Menu -> Camera Settings 1 -> Quality. Change to Raw + JPEG for both RAW and JPG files, or Extra Fine for best JPG only quality.
  - Exit the menu after changing the above. Be sure to physically power off the camera using its own power switch on the top of the camera. If you dont, the settings changed above will not save.
  - To format the memory card, go to Camera Menu -> Setup (toolbox icon) -> Setup6 screen -> Format
  - Some notes on Camera exposure settings:
    - Higher focal length (ie 50mm vs 35mm) is more detail, less field of view. Lower focal length is higher field of view and less detail.
    - Settings for mapping are ISO 200, shutter speed 1/1000, and aperture f/2.8
- AirPixel Air Commander Entire R3 Configuration:
  - Connect to its WiFi hotspot from your PC
  - http://entire/ or http://192.168.10.1/
  - Open ENTIRE’s MENU web page and set UNI-C port to
    - MavLink mode
    - 230400 bps
  - Enable GeoTagging via MENU -> Logging mode-> Direct EXIF (or SD card)
  - Enable HotShoe capturing via MENU -> Capture detection -> Hotshoe sync
  - Set Time Zone to your local time zone
    - MENU -> Settings -> Time Zone Offset
  - Set other options for Geotagging
    - MENU -> Settings
      - XMP Geotagging Section
        - Set geotag roll/pitch/yaw to on
        - Set geotag gps accuracy to on
    - TEXT Log Features Section
      - Append UTC Time to on
      - Append FIX type and HDOP to on
      - Append GPSAccuracy to on
      - Append RangeFinder to on
  - Now you can also preview GPS data and gimbal angles in the Entire’s GUI
    - MENU -> Settings -> GPS Data Preview
    - Data shown in the preview are updated online and should react to gimbal movements
  - Enable slow zoom for the Sony Zoom Lens
    - MENU -> Miscellaneous -> SONY Options -> Use Slower Zooming (set to checked)
  - Have the Air Commander Restart Camera After It Initializes. I noticed that if I dont do this, there are times where the Air Commander was unable to control the camera after first powering on the drone. (I am on the fence if this actually helps. I currently have this disabled.)
    -  MENU -> Miscellaneous -> SONY Options -> Send Power Toggle After Start-Up (set to checked)
  -  MENU -> Miscellaneous -> Dont Reconnect USB After Photo
     -  I set this to checked per the docs at https://airpixel.cz/docs/sony-camera-control/
  - Do a self test
    - MENU -> Configuration Test
- To control the gimbal on the Herelink controller:
  - Ensure you install the latest QGroundControl release for the Herelink: [QGroundControl Herelink Releases](https://github.com/CubePilot/qgroundcontrol-herelink/releases)
  - Then follow [these instructions on Youtube](https://www.youtube.com/watch?v=a-cLzYD7HBk&t=43s) to install the custom APK file for QGroundControl on the Herelink.
  - Also install [AirPixel Air Commander MavCam for HereLink](https://airpixel.cz/docs/herelink-camera-control/)
- HereLink QGroundControl Setup
  - Tap on the gimbal settings in top right menu.
  - Check Enable on Screen Camera Control
  - Set Control Type to Click to Point
  - Check show gimbal Azimuth in map
  - Uncheck show gimbal Azimuth instead of local yaw on top toolbar indicator
- AirPixel Air Commander MavCam for HereLink Setup
  - Swipe up on the widget to see the Control Menu
  - Swipe right on the widget for Settings
    - Check HW Photo Button
    - Check HW Video Button
    - Check HW Wheel
    - Check Joystick
  - Press the GTG button in MavCam widget (for Geotagging control). Set Takeoff detection to enabled.
- Install the Air Commander Mission Planner Camera Controller Plugin
  - [Air Commander Mission Planner Camera Controller Plugin](https://airpixel.cz/docs/missionplanner-camera-control-plugin/)

# Supporting Materials
- [ArduPilot Configuration](../ArduPilot-Config/ArduPilot-Config.md) - This page contains a consolidated list of the all of the configuration done in ArduPilot throughout the videos.

# References 
- [Ardupilot to Gremsy HDMI Quick Release Wiring](https://ardupilot.org/copter/docs/common-gremsy-pixyu-gimbal.html)
- [Gremsy GTune Desktop Software](https://github.com/Gremsy/gTuneDesktop/releases)
- [Gremsy T7 Firmware Releases and Downloads](https://github.com/Gremsy/T7-Firmware/releases)
- [Gremsy T7 Firmware Upgrade Instructions](https://gremsy.com/support/product-support/series-gremsy-t-s/gremsy-t7/gremsy-t7-download)
- [AirPixel Air Commander Setup with Gremsy Gimbal](https://airpixel.cz/docs/gremsy-evo-installation-for-pixhawk/)
- [AirPixel Air Commander Sony Camera Control](https://airpixel.cz/docs/sony-camera-control/)
- [AirPixel Air Commander Using WiFi for camera control](https://airpixel.cz/docs/wifi-for-camera-control/)
- [AirPixel Air Commander MavCam for HereLink](https://airpixel.cz/docs/herelink-camera-control/)
- [AirPixel Air Commander Mission Planner Camera Control Plugin](https://airpixel.cz/docs/missionplanner-camera-control-plugin/)
- [AirPixel Air Commander Firmware Updates](https://airpixel.cz/docs/firmware-update/)
- [QGroundControl Herelink Releases](https://github.com/CubePilot/qgroundcontrol-herelink/releases)
- [PureThemal Mini Flir USB IR Camera Mount 3d Print](https://cults3d.com/en/3d-model/game/pure-thermal-mini-flir-usb-ir-camera-mount) - I had to scale this to 105% for it to fit the USB camera. I used this as the back, and the next file for the top.
- [Hard Enclosure for Purethermal Mini 3d Print](https://cults3d.com/en/3d-model/gadget/hard-enclosure-for-purethermal-mini) - I had to scale this to 105% for it to fit the USB camera. I used this as the front, and the prior file for the back.
- [PTGui](https://ptgui.com/) - software you can create high quality panoramas with.

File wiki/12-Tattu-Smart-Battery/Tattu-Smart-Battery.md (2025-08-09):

This page contains details on the setup of the Tattu smart battery. Tattu Plus batteries with AS150U connectors support DroneCAN which allows the autopilot to retrieve the battery’s total voltage, individual cell voltages, current, temperature and percentage of remaining capacity.

# YouTube Video
- [Hexacopter Drone Build Project – Part 12 Tattu Smart Battery](https://youtu.be/B040AUwVVrQ)
- [How to Update the Firmware on Your Tattu TA3200 Smart Charger | Step-by-Step Guide](https://www.youtube.com/watch?v=zrvEaCpQMPI&t=32s)

# Notes
- I could NOT get the telemetry to reliably read on the CAN bus if the battery was connected to the same CAN port as the HobbyWing motors. In my configuration the motors, GPS, HereFlow, and Cube ID are all connected to CAN1, and the battery is connected to CAN2.
- Be sure to have both CAN ports enabled, and a different driver setup for each through these ArduPilot parameters:
    |Parameter Name|Value|Description|
    |---|---|---|
    |CAN_P1_DRIVER|1||
    |CAN_P2_DRIVER|2||
    |CAN_D1_PROTOCOL|1|DroneCAN|
    |CAN_D2_PROTOCOL|1|DroneCAN|
- On the wiring of the data pins from the battery:
  - CAN_H is the white wire
  - CAN_L is the yellow wire
  - The red wire is NOT connected. 
- TA3200 Charger Firmware updates are done by following these steps (which can be found from [Tattu on Youtube here](https://www.youtube.com/watch?v=PMu2slkg2XQ)):
  - Download latest firmware from the [Tattu downloads page](https://www.grepow.com/downloads.html). It will be under the "TA3200 LiPo Charger Firmware Upgrade Package"
  - Open the update software.
  - Press the left button and holding the button while you power on the charger.
  - Connect the USB cable between the charger and your computer.
  - Press update on the charger firmware update software.
  - Restart the charger and note the new firmware version.
- You enter setup mode on the TA3200 Charger by following these steps (which can be found from [Tattu on Youtube here](https://www.youtube.com/watch?v=xU64uayYcXM)):
  - Quickly press the Left -> Up -> Down buttons in sequence

# Supporting Materials
- [ArduPilot Configuration](../ArduPilot-Config/ArduPilot-Config.md) - This page contains a consolidated list of the all of the configuration done in ArduPilot throughout the videos.

# References 
- Ardupilot Tattu DroneCAN battery guide [can be found here](https://ardupilot.org/plane/docs/common-tattu-dronecan-battery.html).

# Images
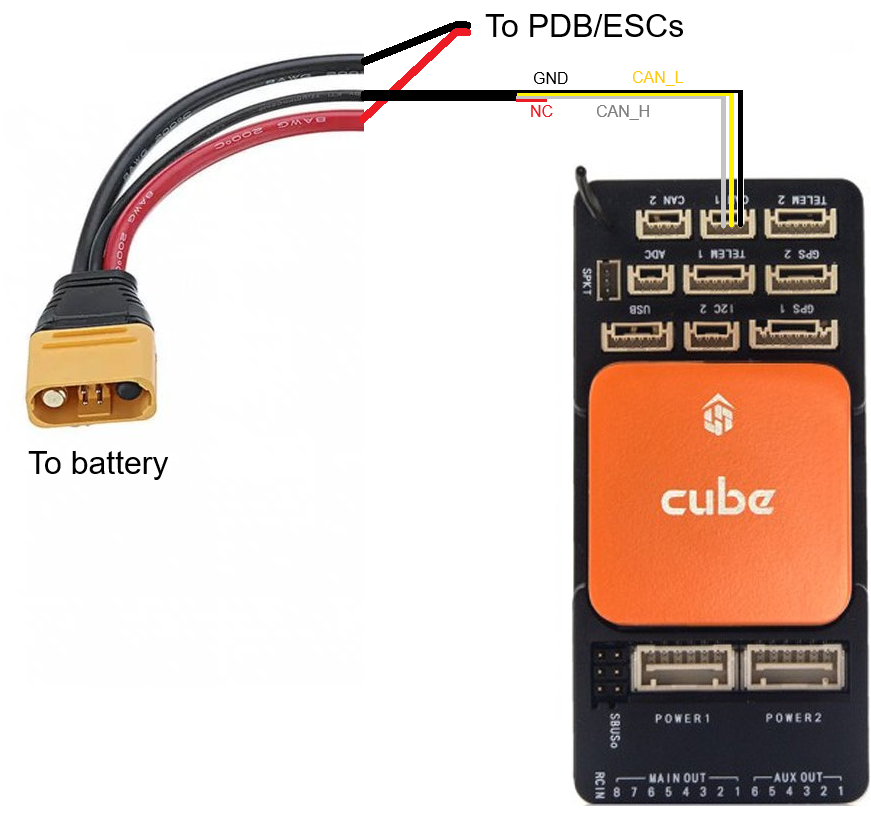
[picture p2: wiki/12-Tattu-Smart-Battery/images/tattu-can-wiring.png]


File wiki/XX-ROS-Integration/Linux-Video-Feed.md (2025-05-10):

# Install X server, GStreamer, and Video4Linux utilities. Stream a USB camera to the HDMI Port.
- First ensure you have ubuntu desktop installed.
- Install packages needed:
```sh
sudo apt update
sudo apt install -y ffmpeg gstreamer1.0-tools gstreamer1.0-plugins-base gstreamer1.0-plugins-good gstreamer1.0-plugins-bad gstreamer1.0-plugins-ugly
sudo apt install -y v4l-utils
sudo apt install -y fbset
sudo apt install -y gstreamer1.0-libcamera
```
- Stop the Login Screen Service
```sh
sudo systemctl stop display-manager
```
- Set the framebuffer output format
```sh
sudo fbset -xres 1024 -yres 768 -depth 16
```
- Automatically Switch to the Correct TTY
Ensure the system is on a TTY console and not stuck on an X session or Wayland. If necessary, switch to TTY1 using:
```sh
sudo chvt 1
```
- Diplay video formats supported by the camera:
```sh
sudo v4l2-ctl --list-formats-ext -d /dev/video4
```
- Output video feed to the local HDMI port:
```sh
sudo gst-launch-1.0 v4l2src device=/dev/video4 ! videoconvert ! fbdevsink
```
OR
```sh
sudo ffmpeg -f v4l2 -video_size 1280x720 -framerate 15 -i /dev/video4 -pix_fmt rgb565le -f fbdev /dev/fb0
```
- Revert to Normal After Use
```sh
sudo systemctl start display-manager
```

# Use Gstreamer to Broadcast to VLC Media Player
- On the linux machine run command:
```
sudo gst-launch-1.0 v4l2src device=/dev/video4 ! videoconvert ! x264enc tune=zerolatency bitrate=500 speed-preset=superfast ! mpegtsmux ! udpsink host=IP_OF_MACHINE_TO_STREAM_TO port=5000
```
- And on the PC running VLC media player do Media > Open Network Stream, and then enter udp://@:5000

# Use Gstreamer to Stream To Mission Planner on Another PC
- On the linux machine run command:
```
sudo gst-launch-1.0 v4l2src device=/dev/video4 ! videoconvert ! x264enc tune=zerolatency bitrate=500 speed-preset=superfast ! rtph264pay config-interval=1 pt=96 ! udpsink host=<MISSION_PLANNER_COMPUTER_IP> port=5600
```
An alternative if have a raspberry pi CSI camera is to use libcamerasrc:
```
gst-launch-1.0 libcamerasrc ! videoconvert ! x264enc tune=zerolatency bitrate=500 speed-preset=superfast ! rtph264pay config-interval=1 pt=96 ! udpsink host=puter port=5600
```

You can also use the tee command to send to multiple computers:
```
gst-launch-1.0 libcamerasrc ! videoconvert ! x264enc tune=zerolatency bitrate=500 speed-preset=superfast ! rtph264pay config-interval=1 pt=96 ! tee name=t \
  t. ! queue ! udpsink host=tims-pc01 port=5600 \
  t. ! queue ! udpsink host=puter port=5600
```

- Mission planner might automatically pick up the video feed when it is started. But if not, right click on the HUD display > Video > Set Gstreamer Source. Enter this in there:
```
udpsrc port=5600 ! application/x-rtp, encoding-name=H264, payload=96 ! rtph264depay ! avdec_h264 ! videoconvert ! autovideosink
```

# Setup a Lightweight RTSP Server on the Linux Machine
- Download a lightweigth RTSP server and install it:
```
mkdir ~/rtsp
cd ~/rtsp
wget https://github.com/bluenviron/mediamtx/releases/download/v1.12.0/mediamtx_v1.12.0_linux_amd64.tar.gz
tar -zxpvf mediamtx_v1.12.0_linux_arm64v8.tar.gz
./mediatx
```
- Use ffmpeg to send your video to the server
```
ffmpeg -f v4l2 -i /dev/video4 -vcodec libx264 -preset ultrafast -tune zerolatency -f rtsp rtsp://localhost:8554/mystream
```
- Now connect to the stream
  - From VLC: rtsp://<your-linux-pc-ip>:8554/mystream
  - From Mission Planner: rtspsrc location=rtsp://<your-linux-pc-ip>:8554/mystream latency=0 ! rtph264depay ! avdec_h264 ! videoconvert ! autovideosink

# Use OpenCV to Display to the HDMI Port
- Install dependencies:
```sh
sudo apt install python3-opencv python3-pillow
```
- Run python program
```python3
```

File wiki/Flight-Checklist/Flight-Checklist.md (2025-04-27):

This page contains a checklist to work through prior to flying the drone.

# Before Flight Prep Checklist – Do Before Heading to Field
1.	Portable Battery Charged
1.	Laptop Charged
1.	HereLink Charged
1.	Drone Battery Charged
1.	Review ArduPilot Configuration Below. Everything set appropriately for flight modes and failsafes?
1.	Will the Gimbal be needed? If not set MNT1_TYPE to 0.
1.	Field Equipment Packed? See list below.
1.	Field Tools Packed? See list below.
1.	Clean rangefinder, proximity sensor, and camera lens.

# Ground Control Station (GCS) Prep Checklist
1.	Enable Phone Mobile HotSpot
1.	Power on Travel Router/Wifi 
1.	Power On Laptop
1.	Is Laptop Connected to Wifi, Can access Internet?
1.	Setup RTK Base Tripod
1.	Connect Here4 Base to Laptop
1.	Connect Coax Cable from Here4 Base to GPS Antenna
1.	Start Mission Planner and Get a Ground Unit Fix

# Drone Flight Checklist
1.	Arms Extended
1.	Arms Secure and Locked in Place?
1.	Battery Installed and Secure
1.	Foam Prop Mounts Removed
1.	Props Positioned Out
1.	Gimbal Connected
1.	HDMI Cable Connected to Gimbal
1.	Power On Drone
1.	Power on HereLink Controller
1.	Connect Mission Planner GCS to HereLink Controller
1.	Is Video Feed Viewable in HereLink?
1.	Can Video Feed Swap to HDMI2 and Back to HDMI1 and Works Properly?
1.	Does Camera Trigger Button Work?
1.	Does Camera Menu Button Work?
1.	Does Camera Zoom Work?
1.	Does Gimbal Move Correctly?
1.	Does Camera Have an SD Card?
1.	Do Flight Modes Toggle Appropriately (Review Below Which Button Maps to Which Flight Modes)
1.	Did GPS Get a Fix?
1.	Is Automated Mission Uploaded Correctly?
1.	Do we want Fence On or Off?

# ArduPilot Configuration to Review
## Important ArduPilot FailSafe Params
- BATT_LOW_VOLT=43.2
- BATT_CRT_VOLT=42
- BATT_FS_LOW_ACT=2 - Action to perform if the low battery failsafe is hit. 2 = RTL
- BATT2_FS_LOW_ACT=2 - Action to perform if the low battery failsafe is hit. 2 = RTL
- BATT_FS_CRT_ACT=1 - Action to perform if the critical battery failsafe is hit. 1 = Land
- BATT2_FS_CRT_ACT=1 - Action to perform if the critical battery failsafe is hit. 1 = Land
- FS_THR_ENABLE=1 The throttle failsafe allows you to configure a software failsafe activated by a setting on the throttle input channel. Set to Enabled, always RTL. If the GPS position is not usable, the copter will change to Land Mode instead.
- FS_THR_VALUE=975 The PWM level in microseconds on channel 3 below which throttle failsafe triggers.
- RC_FS_TIMEOUT=1 RC failsafe will trigger this many seconds after loss of RC.

## Important ArduPilot RTL Params
- RTL_ALT=1500 - The minimum alt above home the vehicle will climb to before returning. If the vehicle is flying higher than this value it will return at its current altitude. Value is in Centimeters.
- RTL_LOIT_TIME=5000 - Time (in milliseconds) to loiter above home before beginning final descent. Value is in milliseconds.

# HereLink Button Setup
## HereLink Button Setup - Flight Modes
On the HereLink controller I configured the A, B, and Home buttons to control my flight modes using the following steps:
-  Flight Mode 1 - Loiter - PWM 0-1230 - Mapped to button A short press, active value 1100, mark as default button
-  Flight Mode 2 - Stabilize - PWM 1231-1360 - Mapped to button A long press, active value 1300
-  Flight Mode 3 - AltHold - PWM 1361-1490 - Mapped to button B short press, active value 1425
-  Flight Mode 4 - Auto - PWM 1491-1620 - Mapped to button B long press, active value 1550
-  Flight Mode 5 - Smart_RTL - PWM 1621-1749 - Mapped to button home short press, active value 1675
-  Flight Mode 6 - Land - PWM 1750+ - Mapped to button home long press, active value 1800

## HereLink Button Setup - Other Buttons
- A Short Press - Loiter Flight Mode
- A Long Press - Stabilize Flight Mode
- B Short Press - AltHold Flight Mode
- B Long Press - Auto Flight Mode
- Home Short Press - RTL Flight Mode
- Home Long Press - Land Flight Mode
- C Short Press – Channel 8 – Enable/Disable Proximity Avoidance
- D Short Press – Channel 6 – Enable/Disable Navigation Lights
- D Long Press – Channel 7 – Enable/Disable Fence Mode

# Fence Setup
In Mission Planner go to the Config->GeoFence tab. Configure the GeoFence settings to control the distance your drone is allowed to go from it's launch point.
- FENCE_ACTION 4 4 = Brake or Land. Set to 0 for report only. 
- FENCE_ALT_MAX 120 Maximum altitude allowed before geofence triggers. Value is in meters. I set to 30 when initially testing drone. 
- FENCE_ALT_MIN -10 Minimum altitude allowed before geofence triggers. Value is in meters. 
- FENCE_AUTOENABLE 0 Auto-enable of fences. Set to Disabled. 
- FENCE_ENABLE 1 Allows you to enable (1) or disable (0) the fence functionality. 
- FENCE_MARGIN 3 Distance that autopilot's should maintain from the fence to avoid a breach. Value is in meters. 
- FENCE_RADIUS 100 Circle fence radius which when breached will cause an RTL. Value is in meters. 
- FENCE_TYPE 7 Bitmask. Set to Max Altitude, Circle Centered on Home, and Inclusion/Exclusion Circles+Polygons 

# Field Equipment to Pack
- Drone
- Battery
- Herelink Controller
- Here4 Base
- RTK GPS Antenna and Tripod
- Coax Cable to Connect Antenna to Here4 Base
- Laptop
- USB Cable to Connect to Flight Controller - both Micro USB and USB-C
- Travel Router/Wifi 
- Travel Router Battery Power
- Cellular Phone with Hotspot
- USB Charger
- Drone Battery Charger
- Sunglasses
- Bug Spray
- Small Folding Table
- Chair
- 4x4 sheet of plywood to field list for takeoff pad

# Field Tool List
- Hex Drivers – 2.5mm, 2mm, and 1.5mm
- Nut Drivers – 7mm, 5.5mm, 5mm
- Zip Ties
- Velcro
- Small Wire Cutters
- Wire Strippers
- Small Pliers
- #1 Phillips Screwdriver
- Flat Head Screwdriver
- Metric Ruler
- Cordless Drill
- Drill Bits

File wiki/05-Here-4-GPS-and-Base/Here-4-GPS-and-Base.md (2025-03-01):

This page contains details on the setup of the Here 4 GPS and Here 4 Base.

The Here 4 GPS is a professional High Precision Dual-band RTK Navigation module. It supports multiple GNSS options such as BeiDou, Galileo, GLONASS, GPS, QZSS.

The Here 4 Base employs RTK (Real-Time Kinematic) technology to offer more precise position estimation compared to standard GNSS systems. Its potential for centimeter-level accuracy greatly enhances flight precision. The Here 4 supports L1 and L5 bands. Utilizing the L5 band delivers improved performance under challenging urban environments. The L5 signals fall within the protected ARNS (aeronautical radio navigation service) frequency band, leading to less RF interference.

# YouTube Video
- [Hexacopter Drone Build Project – Part 5 Here 4 GPS and Base](https://www.youtube.com/watch?v=yGW7yLQpPdI)

# Notes
- If you are going to install dual GPS units, you can take advantage of GPS for Yaw.
- When using dual Here4 units to take advantage of GPS for yaw, set the following:
  - Both units MUST be on the same physical CAN bus from the autopilot. I have mine connected to CAN1.
  - The antennas must be separated by at least 30cm on the vehicle.
  - Ensure no SERIAL ports are setup with GPS protocol (“5”). I had to set SERIAL3_PROTOCOL to -1.
  - Set the following:
    - GPS1_TYPE = 22 (“DroneCAN moving baseline base”)
    - GPS2_TYPE = 23 (“DroneCAN moving baseline rover”)
    - GPS_AUTO_CONFIG = 2 (AutoConfig DroneCAN)
    - GPS_AUTO_SWITCH = 1
    - EK3_SRC1_YAW = 3 (GPS with compass fallback)
    - Set the GPS1_POS_X/Y/Z and GPS2_POS_X/Y/Z parameters for the GPS antennas (see Sensor Position Offset are here). You must establish the relative positions of each GPS location on the vehicle with respect the vehicle’s motion.
    - You will also need to set the GPS1_CAN_OVRIDE and GPS2_CAN_OVRIDE so that the same gps units also map to GPS 1 and GPS2.

# Supporting Materials
- [ArduPilot Configuration](../ArduPilot-Config/ArduPilot-Config.md) - This page contains a consolidated list of the all of the configuration done in ArduPilot throughout the videos.

# References 
- User guide for the Here 4 GPS [can be found here](https://docs.cubepilot.org/user-guides/here-4/here-4-manual).
- User guide for the Here 4 Base [can be found here](https://docs.cubepilot.org/user-guides/here-4/here-4-base).
- [ArduPilot GPS Blending Document](https://ardupilot.org/copter/docs/common-gps-blending.html).
- [GNSS View Tool - use to see constellations in your area](https://app.qzss.go.jp/GNSSView/gnssview.html).
- [GPS for Yaw](https://ardupilot.org/copter/docs/common-gps-for-yaw.html).
- [Supported GPS in ArduPilot](https://ardupilot.org/copter/docs/common-positioning-landing-page.html#common-positioning-landing-page)
- [uBlox u-center](https://www.u-blox.com/en/product/u-center) - GNSS evaluation software for Windows

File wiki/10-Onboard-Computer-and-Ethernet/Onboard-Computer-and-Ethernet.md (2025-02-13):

This page contains details on the installation of a Raspberry Pi 5 companion computer and the setup of a BotBlox SwitchBlox Ethernet switch to create a network onboard the drone.

# YouTube Video
- [Hexacopter Drone Build Project – Part 10 Onboard Computer and Ethernet](https://youtu.be/5UbClGg2NsM)

# Notes
- 192.168.43.1 is Herelink controller IP address when you connect to it through it's WiFi access point mode from a ground control station (i.e., a laptop or computer).
- There is no dhcp provided by the Herelink Air Units. You need to manual set an ip address inside the range eg 192.168.144.0, subnet mask 255.255.255.0. For example, use 192.168.144.50. This will put you within the IP range of the airunit and GCS unit, so they are accessible from the airunit ethernet port.
  - The Airunit and Controller occupy the addresses 192.168.144.10 and 192.168.144.11, so you cannot use these IP addresses for other devices on the network within the drone.
  - Herelink Air Unit is at IP address 192.168.144.10
  - Herelink Controller is at IP address 192.168.144.11
- You can get rtsp video from 192.168.43.1, 192.168.144.10, or 192.168.144.11
- You can get mavlink from 192.168.43.1, 192.168.144.10 (Herelink Air Unit), or 192.168.144.11 (Herelink Controller) port 14552
- To be able to route traffic between the Drone Network and the Ground Control Station Herelink WiFi AP:
  - GCS/Laptop needs a static route to 192.168.144.0/24 via 192.168.43.1
    - To do this, assuming your GCS is a Windows PC, open a command prompt as administrator and run `route add 192.168.144.0 mask 255.255.255.0 192.168.43.1`
    - To make the route persistent across reboots, run it with the -p flag: `route -p add 192.168.144.0 mask 255.255.255.0 192.168.43.1`
  - Companion computer needs a static route for 192.168.43.0/24 via 192.168.144.11
    - To do this temporarily, run the command: `sudo ip route add 192.168.43.0/24 via 192.168.144.11`
    - To do it permanently, simply leave in the routes section in the static IP configuration as shown below.
- RTSP URLs:
  - for the RTSP video stream on the Herelink Controller is: rtsp://192.168.43.1:8554/fpv_stream or rtsp://192.168.144.11:8554/fpv_stream
  - for the RTSP video stream on the Herelink Air Unit is: rtsp://192.168.144.10:8554/H264Video
  - You can connect to that using a tool such as VLC Media Player
- I've found trying to download logs to the Raspberry Pi using Mavlink and Ethernet is very slow. It gets data in 90 byte chunks. For this reason, I added a serial link between the Raspberry Pi and the Kore carrier board.
  - One end connects to the GPS2 (SER4/I2C2) port. This is SERIAL4 in ArduPilot then.
  - TX from the Kore connects to RX on the Raspberry Pi (Pin 10, GPIO15/RXD).
  - RX from the Kore connects to TX on the Raspberry Pi (Pin 8, GPIO14/TXD).
  - Ground from the Kore connects to Groun on the Raspberry Pi. (Pin 39)
  - Then set these ArduPilot parameters:
    - SERIAL4_PROTOCOL = 2 to enable MAVLink 2 on the serial port.
    - SERIAL4_BAUD = 921
  - Then on the Raspberry Pi, follow the instructions in the `Raspberry Pi Serial Port Setup` section below.

# Sudo Setup
- Make it so the ubuntu user can sudo without a password
```sh
sudo visudo
```
Add this line at the end (replace ubuntu with the userid you want to sudo without a password)

```sudo
ubuntu ALL=(ALL) NOPASSWD: ALL
```

# Setting An IP Address on the Raspberry Pi
The following commands will give your Raspberry Pi a static IP address that will allow it to communicate with the Herelink Air Unit, Controller, and the Ground Control Station (if connected through the WiFi AP on the Herelink controller). 

- Open the Netplan configuration file for editing: `sudo vi /etc/netplan/01-netcfg.yaml`
- Edit the configuration file to set the static IP address. The file should look something like this
```
network:
  version: 2
  ethernets:
    eth0:
      addresses:
        - 192.168.144.55/24
      dhcp4: no
      routes:
        - to: 192.168.43.0/24
          via: 192.168.144.11
```
- After saving the file, apply the Netplan configuration with the following command: `sudo netplan apply`
- Verify the configuration. You can check the IP address assignment by using the ip command: `ip addr show eth0`

# Updating Ubuntu Server to Ubuntu Desktop
After installing Ubuntu server, you may wish to enable the graphical desktop. You can do that by running the commands below:
```sh
sudo apt update
sudo apt upgrade
sudo apt install ubuntu-desktop -y
sudo apt install xrdp -y
sudo usermod -aG sudo ubuntu
sudo systemctl set-default graphical.target
sudo reboot
```

# Raspberry Pi Serial Port Setup
To setup the serial port on the Raspberry Pi top be able to connect it to the flight controller, you need to do some configuration on the Pi:
1. Edit /boot/firmware/config.txt
  - On the Raspberry Pi 5 you have to edit `/boot/firmware/config.txt` and set these two params:
  ```
  enable_uart=1
  dtoverlay=uart0
  ```
  - And on a Raspberry Pi 4 you have to edit `/boot/firmware/config.txt` and set these three params instead:
  ```
  enable_uart=1
  dtoverlay=uart0
  dtoverlay=disable-bt
  ```
2. Remove ModemManager, it will conflict with your serial port:
```sh
sudo apt remove modemmanager
```
3. Ensure permissions are set correctly on /dev/ttyAMA0
```sh
sudo chown root:dialout /dev/ttyAMA0
sudo chmod 660 /dev/ttyAMA0
```
4. Add user to the dialout group:
```sh
sudo usermod -aG dialout ubuntu
```
5. Disable agetty on /dev/ttyAMA0
agetty is typically used for serial console access. If you don't need this, disable it. It is possible it isn't enabled already, if not then that's OK:
```sh
sudo systemctl stop serial-getty@ttyAMA0.service
sudo systemctl disable serial-getty@ttyAMA0.service
```
6. Remove serial console access from the boot configuration:
```sh
sudo vi /boot/firmware/cmdline.txt
```
Remove any reference to console=serial0,115200 or console=ttyAMA0.
7. Reboot
```sh
sudo reboot
```
8. To test if it's working, you can try to connect with mavproxy:
```sh
pip3 install mavproxy
mavproxy.py --master=/dev/ttyAMA0 --baudrate=921600
```

# Python and Pymavlink
You may wish to interact with your drone from your companion computer using Python. This section shows the basics of how to communicate with the ArduPilot flight controller.

- [Pymavlink](https://github.com/ArduPilot/pymavlink) is a Python library for generating and parsing MAVLink messages. MAVLink (Micro Air Vehicle Link) is a communication protocol used primarily in drone applications for telemetry and command/control communication.

1. Install dependencies: `sudo apt update && sudo apt install python3-full python3-pip python-is-python3`
1. Create a python virtual environment: `python3 -m venv drone01`
1. Activate virtual environment: `source drone01/bin/activate`
1. Install python libraries into the virtual environment: `pip3 install pymavlink`
1. Try a simple test program to communicate with the flight controller. Create a file named `sample01_simple_mavlink_test.py` and add the contents of [this file](../../src/sample01_simple_mavlink_test/sample01_simple_mavlink_test.py) to it.
1. Run the program: `python sample01_simple_mavlink_test.py`
1. Deactivate the virtual environment: `deactivate`
1. Delete the virtual environment: `rm -rf drone01`

# Stream a video to the Console
You can use these commands to install mplayer, download a sample mp4, and stream it to the console so that it displays on your Herelink.
```sh
sudo apt install mplayer -y
wget https://download.blender.org/peach/bigbuckbunny_movies/BigBuckBunny_320x180.mp4 -O big_buck_bunny.mp4
sudo mplayer -vo fbdev2 big_buck_bunny.mp4
```

# Display an RTSP Stream
Install ffplay or vlc:
```sh
sudo apt install vlc -y
sudo apt install ffmpeg -y
```

Launch the stream:
```sh
# To pull it from the controller:
vlc rtsp://192.168.144.11:8554/fpv_stream
ffplay rtsp://192.168.144.11:8554/fpv_stream

# To pull it from the air unit:
ffplay rtsp://192.168.144.10:8554/H264Video
```

# Install I2C Tools
If you want to connect devices to the I2C bus on the Raspberry Pi, you will want the I2C tools to be able to view devices attached to the bus:
```sh
sudo apt install -y i2c-tools
```
And then you can run a command like to view devices on I2C bus #1:
```sh
i2cdetect -y 1
```

# Supporting Materials
- [Raspberry Pi Imager](https://www.raspberrypi.com/software/) - Download and install the Raspberry Pi Imager from this website.
- [PuTTY SSH Client](https://www.putty.org/) - Free SSH client you can use to connect to your Raspberry Pi.
- [VLC Media Player](https://www.videolan.org/) - Used to view RTSP video streams over a network connection.
- [ArduPilot Configuration](../ArduPilot-Config/ArduPilot-Config.md) - This page contains a consolidated list of the all of the configuration done in ArduPilot throughout the videos.

# References 
- Herelink air unit to botblox switch wiring is shown [on this page](https://ardupilot.org/copter/docs/common-ethernet-vehicle.html).
- ArduPilot discussion post on Ethernet Connected Ardupilot Vehicle Example [can be found here](https://discuss.ardupilot.org/t/ethernet-connected-ardupilot-vehicle-example/117942).
- [Communicating with Raspberry Pi via MAVLink and Serial Port Wiring](https://ardupilot.org/dev/docs/raspberry-pi-via-mavlink.html)

# Pictures
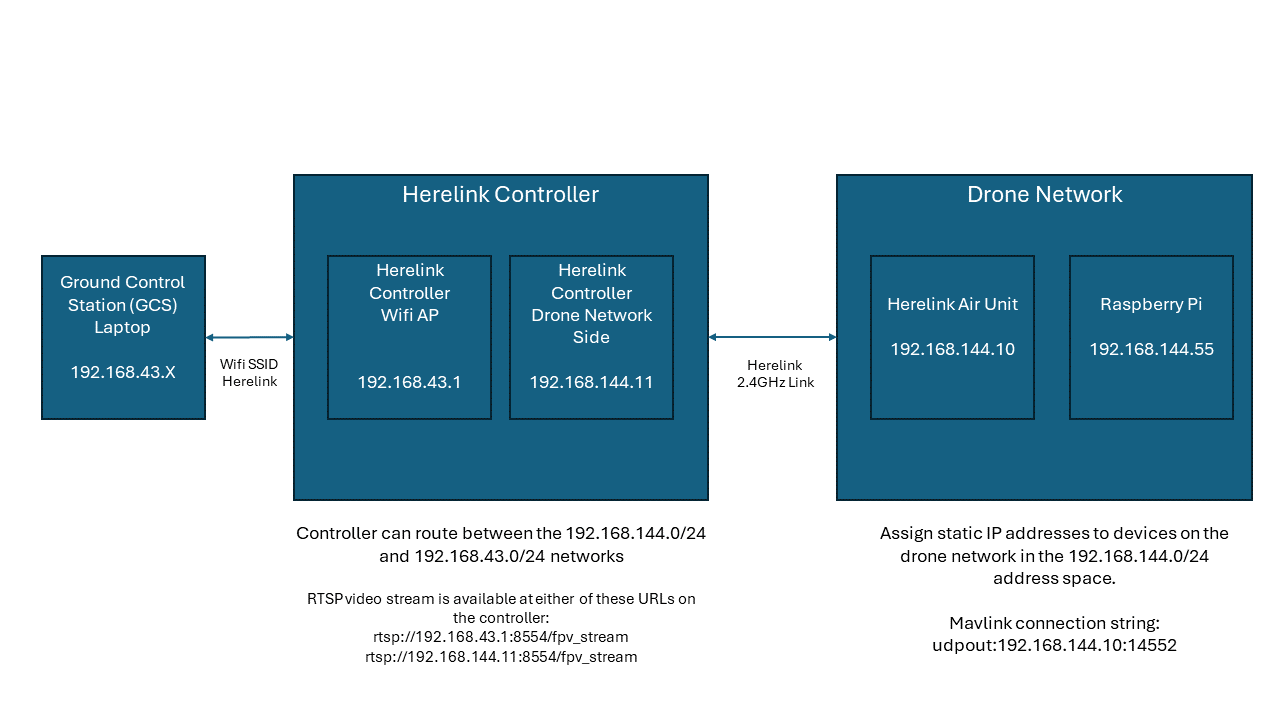
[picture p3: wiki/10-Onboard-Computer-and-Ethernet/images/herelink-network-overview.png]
Herelink Network Overview


Raspberry Pi 5 Pinout
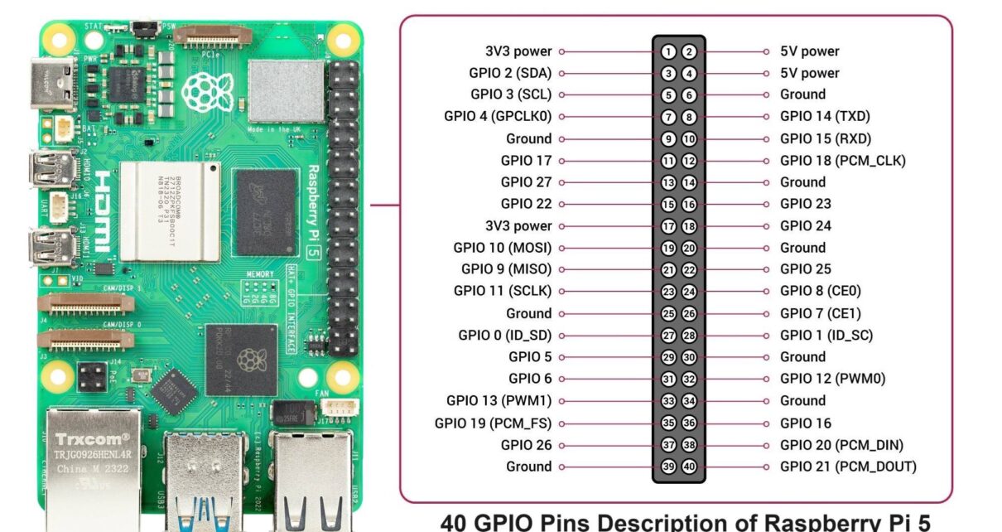
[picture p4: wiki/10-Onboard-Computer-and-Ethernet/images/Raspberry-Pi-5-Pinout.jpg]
Raspberry Pi 5 Pinout


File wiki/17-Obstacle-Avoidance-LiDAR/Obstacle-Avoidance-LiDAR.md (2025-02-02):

This page contains details on setting up the LightWare S45/B LiDAR.

# YouTube Video
- [Hexacopter Drone Build Project – Part 17 Obstacle Avoidance LiDAR](https://youtu.be/x13RS9YKt_g)

# Notes
- I connected the LiDAR to an Matek L431 AP_PERIPH board. This allows me to convert the serial interface of the LiDAR to DroneCAN.

- Setup the LightWare SF45/B LiDAR to be a DroneCAN device using a [Matek AP_PERIPH CAN Node L431 Board](https://www.mateksys.com/?portfolio=can-l431)
  - You must first install the latest firmware to enable seeing the proximity sensor parameters.
  - Download the latest firmware from here for the L431 board (download the .bin file): https://firmware.ardupilot.org/AP_Periph/stable/MatekL431-Proximity/
  - In Mission Planner, go to Setup->Optional Hardware->DroneCAN/UAVCAN
  - Connect to the CAN interface (CAN1 or CAN2) that your device L431 device is connected to.
  - In the menu button on the row for your device, press update. Select No when it asks to search the internet for an update.
  - You will be prompted for the firmware file to load. Select the .bin file downloaded earlier.
  - After updating, select the menu button again to open the parameters for the L431 node.
  - Refresh params in the L431 and then also set:
    - PRX_BAUDRATE=115200
    - PRX_PORT=2
    - PRX1_TYPE=8
    - PRX1_ORIENT=0
    - PRX1_YAW_CORR=0
    - PRX1_IGN_ANG1 and PRX1_IGN_WID1 parameters allow defining zones around the vehicle that should be ignored. For example to avoid a 20deg area to the right, set PRX1_IGN_ANG1 to 90 and PRX1_IGN_WID1 to 20.
  - Now go into Mission Planner->Config->Full Parameter List and set:
    - PRX1_TYPE=14
    - PRX1_MIN=0.2
    - PRX1_MAX=40
- You can set various obstacle avoidance settings on the flight controller as well. I left most of the defaults in place (except for AVOID_ALT_MIN), which were:
  - AVOID_ALT_MIN=1.5 (Minimum altitude (in meters) above which proximity based avoidance will start working. This requires a valid downward facing rangefinder reading to work. Set zero to disable.)
  - AVOID_BEHAVE=1 (Avoidance behaviour of stop)
  - AVOID_DIST_MAX=5 (Distance from object at which obstacle avoidance will begin in non-GPS modes)
  - AVOID_ENABLE=3 (Bitmask for Fence and Proximity)
  - AVOID_MARGIN=3 (Vehicle will attempt to stay at least this distance (in meters) from objects while in GPS modes)
- To see what the proximity sensor sees, in Mission Planner press CTRL-F. Press the button in the popup window labeled "Proximity".
- ArduPilot recommends setting up an RC Channel to be able to turn on and off proximity avoidance.
  - Set RC8_OPTION=40
  - I then mapped Channel 8 to button C on the HereLink controller. 

# Supporting Materials
- [ArduPilot Configuration](../ArduPilot-Config/ArduPilot-Config.md) - This page contains a consolidated list of the all of the configuration done in ArduPilot throughout the videos.
- [3d Printed Lid](../../3d-print-files/drone-top-lid/Drone%20Top%20Lid.stl) - This is the lid to 3d print with mounting holes for the LiDAR.

# References 
- [Ardupilot LightWare SF45/B 350 Lidar Setup Page](https://ardupilot.org/copter/docs/common-lightware-sf45b.html)
- [LightWare Studio](https://lightwarelidar.com/resources-software/) - use this for testing your LiDAR through your PC and a USB connection.
- Download the latest proximity sensor firmware [from here for the L431 board (download the .bin file)](https://firmware.ardupilot.org/AP_Periph/stable/MatekL431-Proximity/)

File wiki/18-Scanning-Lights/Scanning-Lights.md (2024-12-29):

This page contains details on how I added an WS2812B LED light strip and connected it to the Raspberry Pi to create a scanning pattern, similar to the lights from a Cylon or Knight Rider car, on the face of the drone.

# YouTube Video
- [Hexacopter Drone Build Project – Part 18 Scanning Lights](https://youtu.be/pLxJSA_ptMY)

# Notes
- Connect the 5v wire from the LED light strip to the 5v supply coming from the BEC. Also connect the ground wire to the 5v BEC, AND connect it to the ground pin on the raspberry pi. (The device needs a common ground for good data transfers.)
- Connect the data line from the LED light strip to GPIO10 (MOSI) on the raspberry pi. Put a 330 ohm resistor in series between the LED light strip and the Raspberry Pi GPIO pin.
- Create a python environment and install the [Pi5Neo library](https://pypi.org/project/Pi5Neo/).
```sh
sudo apt update
sudo apt install python3-pip

python3 -m venv scanning_leds
source scanning_leds/bin/activate

pip3 install pi5neo
```

- Write a script to control the LEDs. Make a file named led_test.py and put the following in it:
```sh
from pi5neo import Pi5Neo

# User-Configurable Variables
NUM_LEDS = 97               # Total number of LEDs

# Initialize the Pi5Neo class with the specified number of LEDs and an SPI speed of 800kHz
neo = Pi5Neo('/dev/spidev0.0', NUM_LEDS, 800)

# Fill the strip with a red color
neo.fill_strip(255, 0, 0)
neo.update_strip()  # Commit changes to the LEDs

# Set the 5th LED to blue
neo.set_led_color(4, 0, 0, 255)
neo.update_strip()   
```

- Run the script
```sh
python3 led_test.py
```

- Deactivate and remove the virtual environment (optional):
```sh
deactivate
rm -rf scanning_leds
```

# Sample Scripts
- [This script](../../src/sample03_neopixel_examples/loading_bar.py) will just start at one end and light up one LED at a time making a loading bar type of effect. Mainly used to demo the functions that interface with the light strip.
- [This script](../../src/sample03_neopixel_examples/cylon_scan.py) will make a scanning LED pattern where the strip is lit up in red, and 7 LEDs will "scan" back and forth in a blue color.
- [This script](../../src/sample03_neopixel_examples/cylon_scan_dual_end.py) will make a scanning LED pattern where the strip is lit up in red, and the scanning LEDs start at each end of the strip, move toward the center, and then reverse direction back to each end.

# Supporting Materials
- [ArduPilot Configuration](../ArduPilot-Config/ArduPilot-Config.md) - This page contains a consolidated list of the all of the configuration done in ArduPilot throughout the videos.
- [3d Printed Lid](../../3d-print-files/drone-top-lid/Drone%20Top%20Lid.stl) - This is the lid to 3d print with mounting holes for the LiDAR.
- [3d Printed Led Channel for Lid](../../3d-print-files/drone-top-lid/Drone%20Top%20Lid%20LED%20Channel.stl) - This is the channel for the LEDs that fits around the lid.
- [3d Printed Led Channel Cover](../../3d-print-files/drone-top-lid/Drone%20Top%20Lid%20LED%20Face.stl) - This is the cover to the LED channel. Print this with translucent material.

# References 
NA

# Pictures
Raspberry Pi 5 Pinout
Raspberry Pi 5 Pinout

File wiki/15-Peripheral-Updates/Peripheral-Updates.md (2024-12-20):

This page contains details on a variety of miscellaneous updates made to the peripherals of the drone.
- 3d printing a new top lid for the drone.
- Updating the payload configuration.
- Adding a second Here4 GPS and configuring GPS for Yaw.
- Disabling the HereFlow Range Finder.
- Setting up the TFMini-S Range Finder to to be a DroneCAN device using a Matek AP_PERIPH CAN Node L431 Board.

# YouTube Video
- [Hexacopter Drone Build Project – Part 15 Peripheral Updates](https://youtu.be/fCVuGHLcOwo)

# Notes
At this stage, I did a bunch of little modifications and cleanup to the overall hardware of the drone including:
- Added a second Here4 GPS to the drone.
- Designed and printed a new top lid for the drone. The STL and Autodesk Fusion files for the 3d printed top lid are [located here](../../3d-print-files/drone-top-lid/).
- Replaced the stock 12mm payload carbon fiber tubes that came with the drone with longer 330mm ones from Amazon.
- Bought a longer 6-Pin JST-GH Twisted Pair - MRC0212 - 1000mm length cable from 3DR in order to make the serial connection from the gimbal to the Kore carrier board. Its a 6 pin connector and wire designed for I2C, but I removed 3 wires and swapped TX/RX on one end to make it work for the gimbal.
- Cut an 8"x8" sheet of ABS plastic down to a 2"x8" and a 3"x8" strip, and mounted them to the payload carbon fiber tubes with pipe clamps.
- Ran USB cables with USB-C and Micro USB ends to the front ABS plastic sheet. Both USB cables connect to the Raspberry Pi in the drone frame. Connect the USB-C cable to the USB 3.0 port (the blue one) on the Raspberry Pi.
- Mounted an Intel Realsense 435 Depth Camera to the front ABS plastic sheet.
- Mounted the HereFlow module and TFMini-S LiDAR to the ABS plastic sheets.
- Mounted the Gremsy Dampening plate and HDMI Hyper Quick release (see next video for more details though).
- Disabled the HereFlow Range Finder (but left the optical flow components active). Moved the TFMini-S from RNGFND2 to RNGFND1
- Setup the TFMini-S LiDAR to be a DroneCAN device using a [Matek AP_PERIPH CAN Node L431 Board](https://www.mateksys.com/?portfolio=can-l431)
  - You must first install the latest firmware to enable seeing the rangefinder parameters.
  - Download the latest firmware from here for the L431 board (download the .bin file): https://firmware.ardupilot.org/AP_Periph/stable/MatekL431-Rangefinder/
  - In Mission Planner, go to Setup->Optional Hardware->DroneCAN/UAVCAN
  - Connect to the CAN interface (CAN1 or CAN2) that your device L431 device is connected to.
  - In the menu button on the row for your device, press update. Select No when it asks to search the internet for an update.
  - You will be prompted for the firmware file to load. Select the .bin file downloaded earlier.
  - After updating, select the menu button again to open the parameters for the L431 node.
  - Set RNGFND1_TYPE to 20 and press write params.
  - Refresh params in the L431 and then also set:
    - RNGFND_BAUDRATE=115200
    - RNGFND_PORT=2
    - RNGFND_GNDCLEAR=set to distance in centimeters that your rangefinder reads to the ground.
    - RNGFND_MAX_CM=600
    - RNGFND_MIN_CM=10
  - Now go into Mission Planner->Config->Full Parameter List
    - Set RNGFND1_TYPE=24
  - If you are going to setup multiple rangefinders, then you must open the DroneCAN parameters for the device and set the CAN node ID to a unique number. Then you must set RNGFND1_ADDR to the node ID you assigned to the L431 device. For example I used 45 for my TFMini-S and 46 for my HereFlow rangefinder. Dont use an ID for an existing device listed in the Setup->Optional Hardware->DroneCAN/UAVCAN list either.
  - You dont want two identical lidar pointing in the same direction. The most likely outcome is that the lidar will become confused if they pickup the laser sent from the other lidar.
- Configured the POS_X, POS_Y, and POS_Z parameters for the 2 GPS', rangefinder, and HereFlow.
- If you are going to install dual GPS units, you can take advantage of GPS for Yaw.
- When using dual Here4 units to take advantage of GPS for yaw, set the following:
  - Both units MUST be on the same physical CAN bus from the autopilot. I have mine connected to CAN1.
  - The antennas must be separated by at least 30cm on the vehicle.
  - Ensure no SERIAL ports are setup with GPS protocol (“5”). I had to set SERIAL3_PROTOCOL to -1.
  - Set the following:
    - GPS1_TYPE = 22 (“DroneCAN moving baseline base”)
    - GPS2_TYPE = 23 (“DroneCAN moving baseline rover”)
    - GPS_AUTO_CONFIG = 2 (AutoConfig DroneCAN)
    - GPS_AUTO_SWITCH = 1
    - Set the GPS1_POS_X/Y/Z and GPS2_POS_X/Y/Z parameters for the GPS antennas (see Sensor Position Offset are here). You must establish the relative positions of each GPS location on the vehicle with respect the vehicle’s motion.

# Supporting Materials
- [ArduPilot Configuration](../ArduPilot-Config/ArduPilot-Config.md) - This page contains a consolidated list of the all of the configuration done in ArduPilot throughout the videos.

# References 
- Download the latest range finder firmware [from here for the L431 board (download the .bin file)](https://firmware.ardupilot.org/AP_Periph/stable/MatekL431-Rangefinder/)
- [ArduPilot GPS Blending Wiki Page](https://ardupilot.org/copter/docs/common-gps-blending.html)
- [ArduPilot Sensor Position Offset Compensation Wiki Page](https://ardupilot.org/copter/docs/common-sensor-offset-compensation.html)
- [GPS for Yaw](https://ardupilot.org/copter/docs/common-gps-for-yaw.html).
- [Supported GPS in ArduPilot](https://ardupilot.org/copter/docs/common-positioning-landing-page.html#common-positioning-landing-page)

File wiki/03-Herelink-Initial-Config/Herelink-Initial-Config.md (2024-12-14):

This page contains details on the initial unboxing and setup of the Herelink controller and air unit.

# YouTube Video
- [Hexacopter Drone Build Project – Part 3 Herelink Unboxing and Setup](https://youtu.be/6hCZ1OqMMvg)

# Notes
- Dont forget to set the time and time zone correctly on the controller.
- Be sure to enable video sharing in the Herelink controller.
- In the Joystick settings, 
  - Change the default channel for the wheel at the top from channel 5 to 16. This is because ArduPilot is setup for channel 5 to control flight modes.
  - Check the Wheel Acc setting
  - Reverse the hand wheel as well so when you push it to the right it outputs a higher pulse on sbus out.
- Flight Mode Mapping
  - On the HereLink controller in the settings area, go to the buttons tab.
  - Map a short press of button A to channel 5. Set it to a toggle (T) button. Set default value to 1000, and active value to 2000. Then in Mission Planner go toi Setup->Flight Modes. You can then set Flight Mode 1 to Stabilize and Flight Mode 6 to Loiter.
  - Or here's another mapping example for more advanced and multiple flight mode mapping to support many modes:
    -  Flight Mode 1 - Loiter - PWM 0-1230 - Mapped to button A short press, active value 1100, mark as default button
    -  Flight Mode 2 - AutoTune - PWM 1231-1360 - Mapped to button A long press, active value 1300
    -  Flight Mode 3 - AltHold - PWM 1361-1490 - Mapped to button B short press, active value 1425
    -  Flight Mode 4 - Stabilize - PWM 1491-1620 - Mapped to button B long press, active value 1550
    -  Flight Mode 5 - RTL - PWM 1621-1749 - Mapped to button home short press, active value 1675
    -  Flight Mode 6 - Land - PWM 1750+ - Mapped to button home long press, active value 1800
- In Mission Planner go to the Setup->FailSafe tab. Configure the radio failsafe to Enabled always RTL, and an FS Pwm of 975
- In Mission Planner you can also go to the Config->User Params tab and map actions to other channels. For example you could map channel 7 to fence enable/disable. This would be the same as setting RC7_OPTION to a value of 11. Other fun things, for example, you could map it to the lost copter sound.
- Docs on radio calibration [can be found here](https://ardupilot.org/copter/docs/common-radio-control-calibration.html).
- Be sure to test the controls in Mission Planner. Move the transmitter’s roll, pitch, throttle and yaw sticks and ensure the green bars move in the correct direction:
  - For roll, throttle and yaw channels, the green bars should move in the same direction as the transmitter’s physical sticks.
  - For pitch, the green bar should move in the opposite direction to the transmitter’s physical stick.
  - If one of the green bars moves in the incorrect direction reverse the channel in the transmitter itself. If it is not possible to reverse the channel in the transmitter you may reverse the channel in ArduPilot by checking the “Reversed” checkbox (Plane and Rover only). If the checkbox is not visible it is possible to reverse the channel by directly changing the RCx_REVERSED parameter (where “x” is the input channel from 1 to 4).
- Change the baud rate of the Air Unit from 57600 to 115200. To do this, open the herelink settings, go to Airunit, select 115200 for the baudrate and click Reset Baud.

## Downloading Offline Maps in QGroundControl
You may wish to download maps locally for when you will be running missions in areas without internet connectivity. With the maps downloaded, you can plan missions in QGroundControl while offline in the field. The downloaded map tiles will be used automatically by QGroundControl when you're not connected to the internet.

To download maps in QGroundControl for offline use, follow these steps:
- Open QGroundControl on the Herelink controller.
- Click on the Q icon in the top-left corner to open the main menu.
- In the settings, choose the Offline Maps option.
- Click on Add New Set.
- Navigate to the area you plan to operate in by dragging the map.
- Use the zoom controls to set the desired zoom levels. The number of tiles to be downloaded will increase with more zoom levels selected.
- Name the tile set.
- Click Download to start the process.

To manage offline maps:
- After the download completes, the map tiles will be stored locally on your device.
- You can manage these offline maps under the Manage Tiles section, where you can delete or add more tiles as needed.

# References 
## Herelink User Guides
- User guides for the Herelink [can be found here](https://docs.cubepilot.org/user-guides/herelink/herelink-user-guides).
- Many thanks to Painless360 for their video which gave me the info needed to perform this process. Be sure to [watch their video here](https://www.youtube.com/watch?v=DVPRaErKsn0&t=2167s).
- [Herelink how to install a custom app](https://www.youtube.com/watch?v=a-cLzYD7HBk&t=56s) - Shows how to install an APK file on your Herelink controller, such as the Siyi apps.
- [QGroundControl Herelink Releases](https://github.com/CubePilot/qgroundcontrol-herelink/releases)
- [AirPixel Air Commander MavCam for HereLink](https://airpixel.cz/docs/herelink-camera-control/)

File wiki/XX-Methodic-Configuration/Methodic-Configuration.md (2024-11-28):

This page contains details on performing the methodic configuration steps for the ArduPilot software on the drone.

# THIS PAGE IS INCOMPLETE AND A WORK IN PROGRESS

# YouTube Video
- [Hexacopter Drone Build Project – Part XX Methodic Configuration](https://youtu.be/XXX)
- [Hexacopter Drone Build Project – First Flight](https://www.youtube.com/watch?v=HhvRLNxARRs)

# Notes
- Read the blog post [How to methodically configure and tune any ArduCopter Blog Post](https://discuss.ardupilot.org/t/how-to-methodically-configure-and-tune-any-arducopter/110842) several times. It tooks me several reads before it really started to sink in.
- You may be in a hurry to skip steps you understand. Dont. This utility had me exploring areas of the documentation I have never read, and using tools I did not know existed. Think of it as a great structured classroom for learning how to tune your drone.
- Take the time to understand why each parameter is set the way it is.
- For Temperature Calibration:
  - I performed step 2, to enable temperature calibration. Power off drone. Let flight controller get cold. Power on drone. Wait for beeps to stop, meaning calibration is finished. Power off drone. Power drone back on and set LOG_DISARMED=0 so it doesnt start overwriting logs. Also set LOG_BITMASK back to default. Download the .bin log file from the flight controller and then perform step 3 and upload the log file.
- Here is how I configured the Notch Filters:
  - Since I use ESC telemetry, this page recommends to set the INS_HNTCH_FREQ below the hover frequency. https://ardupilot.org/copter/docs/common-esc-telem-based-notch.html
  - Since I'm using multi-source, and I have 6 motors, I set INS_HNTCH_BW = INS_HNTCH_FREQ / number of motors
  - I did a hover test flying for about 50 seconds. Reviewed the logs in Mission Planner and got the average RPMs across all motors during a stable hover period. That was 2434. I divided by 60 to get 40.57.
  - I set my base frequency INS_HNTCH_FREQ to 36 then.
  - I then set the INS_HNTCH_BW to 6
  - On INS_HNTCH_OPTS, I set it to update the harmonic notch at the main loop rates used by the aircraft.
  - Open the log in the ArduPilot Filter Review tool. Highlight about 45 seconds of stable hover flight.
  - Set the amplitude scale to Linear. This is in the graph of Amplitude by Frequency.
  - Zoom in to the spikes so I can see them more clearly.
  - Set INS_HNTCH_FREQ to 36.
  - Then use the filter tool with as light a touch as possible, enabling as few harmonics with the lowest bandwidth and attenuation as reasonably flattens the noise peaks.
  - I did several test flights, and ultimately I was only able to enable the filter on the 1st harmonic as I had to select the option to enable it on all IMUs. When all IMUs were not selected the drone was very unstable. And with more harmonics selected than 1 and enabled on all IMUs the auto pilot would throw an error at boot.

# Supporting Materials
- [My Drones Methodic Configuration Directory](../../ardupilot-methodic-configurator/Hexacopter/) - This folder contains my methodic configuration. Use it for your own starting point.
- [ArduPilot Configuration](../ArduPilot-Config/ArduPilot-Config.md) - This page contains a consolidated list of the all of the configuration done in ArduPilot throughout the videos.

# References 
- [How to methodically configure and tune any ArduCopter Blog Post](https://ardupilot.github.io/MethodicConfigurator/TUNING_GUIDE_ArduCopter)
- [ArduPilot Methodic Configurator User Manual](https://github.com/ArduPilot/MethodicConfigurator/blob/master/USERMANUAL.md)
- [Methodic Configurator releases and downloads can be found here](https://github.com/ArduPilot/MethodicConfigurator/releases)
- [ArduPilot Web Tools](https://firmware.ardupilot.org/Tools/WebTools/)
- [ArduPilot Hardware Report Utility](https://firmware.ardupilot.org/Tools/WebTools/HardwareReport/)
- [ArduPilot Online Log Viewer](https://plotbeta.ardupilot.org/)
- [ArduPilot Filter Review Tool](https://firmware.ardupilot.org/Tools/WebTools/FilterReview/)
- [Follow the instructions from Peter Hall on his Blog Post to configure the Harmonic Notch filter(s)](https://discuss.ardupilot.org/t/new-fft-filter-setup-and-review-web-tool/102572).
- [ArduPilot MAGFit Tool](https://firmware.ardupilot.org/Tools/WebTools/MAGFit/)
- [QuikTune LUA Script Documentation and Scripts](https://ardupilot.org/copter/docs/quiktune.html)
- [Scripted MagFit flightpath generation](https://discuss.ardupilot.org/t/scripted-magfit-flightpath-generation/97536)
- [Downloading and Analyzing Data Logs in Mission Planner](https://ardupilot.org/copter/docs/common-downloading-and-analyzing-data-logs-in-mission-planner.html)

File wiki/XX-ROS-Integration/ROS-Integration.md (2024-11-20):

# THIS PAGE IS INCOMPLETE AND A WORK IN PROGRESS

This page contains details on installing ROS2 on the Raspberry PI and integrating it with the flight controller.

# YouTube Video
- [Hexacopter Drone Build Project – Part XX ROS Integration](https://youtu.be/XXX)

# Notes
- Make sure you have a Raspberry Pi with Ubuntu 24.04 installed on it first. See the [Onboard-Computer-and-Ethernet](../10-Onboard-Computer-and-Ethernet/Onboard-Computer-and-Ethernet.md) page and associated video if you havent done that yet.
ros

# ROS2 Installation Notes
- Follow the instructions to install ROS2 on your Raspberry Pi by following the guide for [Installing ROS2 on Ubuntu 24.04](https://docs.ros.org/en/jazzy/Installation/Ubuntu-Install-Debs.html). I installed the Recommended Desktop Install wehich includes ROS, RViz, demos, tutorials. You need this to run the talker/listener demo in the install instructions.
- Edit ~/.bashrc to add the following line to it so your ROS environment is configured every time you login:
```sh
source /opt/ros/jazzy/setup.bash
```
- Install MAVROS for ROS 2 to use ROS 2 to read a MAVLink stream:
```sh
sudo apt install ros-jazzy-mavros ros-jazzy-mavros-extras
```
- Install the geopgraphic lib
```sh
wget https://raw.githubusercontent.com/mavlink/mavros/master/mavros/scripts/install_geographiclib_datasets.sh
sudo bash ./install_geographiclib_datasets.sh
```
- Verify the geographic lib installation:
```sh
ls /usr/share/GeographicLib/geoids/
# You should see the egm96-5.pgm file, among others, in this directory.
```

# Starting MAVROS
MAVROS is a ROS package that allows users to control drones using the MAVLink protocol. MAVROS can convert between ROS topics and MAVLink messages, allowing ArduPilot vehicles to communicate with ROS.
On the Raspberry Pi, run the following command to start the MAVROS bridge. This command launches the MAVROS node with the specified configuration, connecting to the Herelink Air Unit at 192.168.144.10 via UDP on port 14552 and setting up a Ground Control Station (GCS) URL for communication.
```sh
ros2 launch mavros apm.launch fcu_url:=udp://:14552@192.168.144.10 gcs_url:=udp://@
```

In another SSH window you should now be able to see the nodes and topics by running these commands:
```sh
ros2 node list
ros2 topic list
```

You can print out the messages about your battery health with this command:
```sh
ros2 topic echo /mavros/battery
```

Print out the current flight mode with this command:
```sh
ros2 topic echo /mavros/state
```

# Supporting Materials
- [ArduPilot Configuration](../ArduPilot-Config/ArduPilot-Config.md) - This page contains a consolidated list of the all of the configuration done in ArduPilot throughout the videos.

# References 
- [Installing ROS2 Jazzy on Ubuntu 24.04](https://docs.ros.org/en/jazzy/Installation/Ubuntu-Install-Debs.html)

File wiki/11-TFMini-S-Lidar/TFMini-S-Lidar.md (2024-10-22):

This page contains details on the setup of the Benewake TFMini-S Lidar. This Lidar connects using a serial interface.

Performance characteristics are:
- Measurement Range: 0.1 to 12 meters (indoor conditions) and 0.1 to 7 meters (outdoor conditions).
- Accuracy: ±6 cm within 0.1 to 6 meters; ±1% of distance within 6 to 12 meters.
- Resolution: 1 cm.

# YouTube Video
- [Hexacopter Drone Build Project – Part 11 TFMini-S Lidar](https://youtu.be/6i_XVjCSzAI)

# Notes
- TX from the Lidar connects to RX on the Kore carrier board.
- RX from the Lidar connects to TX on the Kore carrier board.
- See pictures below for examples.
- You can also setup this LiDAR to be a DroneCAN device using a [Matek AP_PERIPH CAN Node L431 Board](https://www.mateksys.com/?portfolio=can-l431)
  - You must first install the latest firmware to enable seeing the rangefinder parameters.
  - Download the latest firmware from here for the L431 board (download the .bin file): https://firmware.ardupilot.org/AP_Periph/stable/MatekL431-Rangefinder/
  - In Mission Planner, go to Setup->Optional Hardware->DroneCAN/UAVCAN
  - Connect to the CAN interface (CAN1 or CAN2) that your device L431 device is connected to.
  - In the menu button on the row for your device, press update. Select No when it asks to search the internet for an update.
  - You will be prompted for the firmware file to load. Select the .bin file downloaded earlier.
  - After updating, select the menu button again to open the parameters for the L431 node.
  - Set RNGFND1_TYPE to 20 and press write params.
  - Refresh params in the L431 and then also set:
    - RNGFND_BAUDRATE=115200
    - RNGFND_PORT=2
    - RNGFND_GNDCLEAR=set to distance in centimeters that your rangefinder reads to the ground.
    - RNGFND_MAX_CM=600
    - RNGFND_MIN_CM=10
  - Now go into Mission Planner->Config->Full Parameter List
    - Set RNGFND2_TYPE=24
- If you are going to setup multiple rangefinders, then you must open the DroneCAN parameters for the device and set the CAN node ID to a unique number. Then you must set RNGFND1_ADDR to the node ID you assigned to the L431 device. For example I used 45 for my TFMini-S and 46 for my HereFlow rangefinder. Dont use an ID for an existing device listed in the Setup->Optional Hardware->DroneCAN/UAVCAN list either.
- You dont want two identical lidar pointing in the same direction. The most likely outcome is that the lidar will become confused if they pickup the laser sent from the other lidar.

# Supporting Materials
- [ArduPilot Configuration](../ArduPilot-Config/ArduPilot-Config.md) - This page contains a consolidated list of the all of the configuration done in ArduPilot throughout the videos.

# References 
- Ardupilot TFMini guide [can be found here](https://ardupilot.org/copter/docs/common-benewake-tfmini-lidar.html).
- Download the latest firmware [from here for the L431 board (download the .bin file)](https://firmware.ardupilot.org/AP_Periph/stable/MatekL431-Rangefinder/)

# Pictures
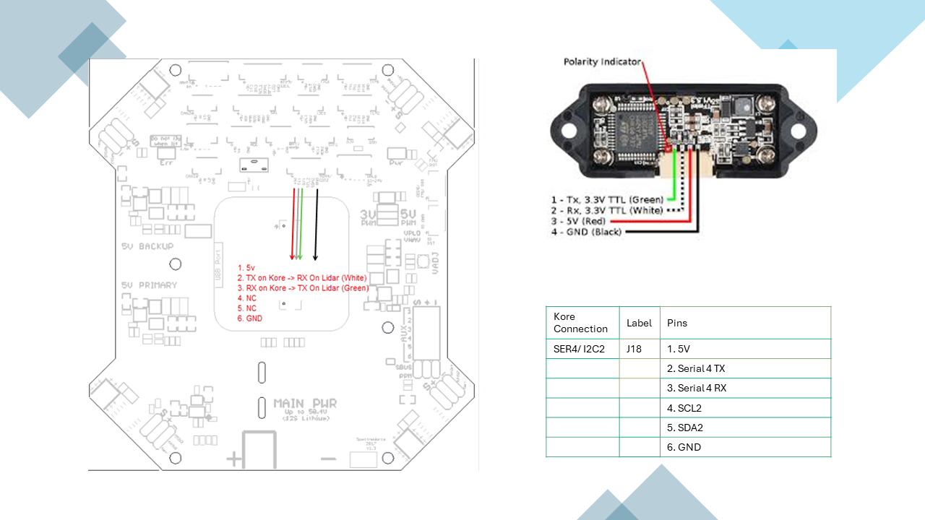
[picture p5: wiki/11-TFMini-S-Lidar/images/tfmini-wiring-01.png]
Wiring Overview to Kore Carrier Board


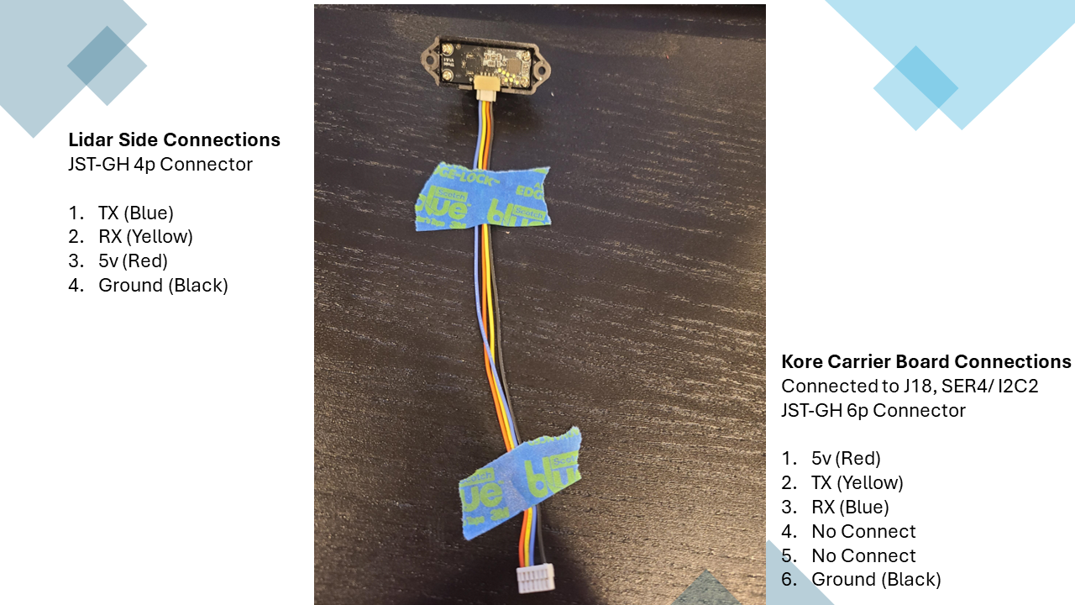
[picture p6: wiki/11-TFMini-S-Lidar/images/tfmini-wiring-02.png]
Wiring Example


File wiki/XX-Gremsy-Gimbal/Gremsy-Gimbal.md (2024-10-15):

This page contains details on setting up the Gremsy T7 Gimbal with the drone.

# YouTube Video
- [Hexacopter Drone Build Project – Part XX Gremsy T7 Gimbal](https://youtu.be/XXX)

# Notes
- I replaced the stock 12mm payload carbon fiber tubes that came with the drone with longer 330mm ones from Amazon.
- I bought a longer 6-Pin JST-GH Twisted Pair - MRC0212 - 1000mm length cable from 3DR in order to make the serial connection from the gimbal to the Kore carrier board. Its a 6 pin connector and wire designed for I2C, but I removed 3 wires and swapped TX/RX on one end to make it work for the gimbal.
- Ensure you load the latest firmware, 7.7.1 or later! Download from https://github.com/Gremsy/T7-Firmware/releases
  - NOTE: Gyro MUST be calibrated after upgrading completely.
    Open gTune --> SETTINGS --> GYRO --> CALIBRATE
    NOTE: Users should load the recommended gimbal parameters and perform an AUTO-TUNE process.
    Open gTune --> SETTINGS --> STIFFNESS --> AUTOTUNE
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

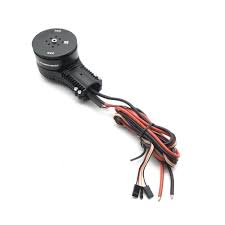
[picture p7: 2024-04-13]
wiki/06-Motors/images/motor2.jpg

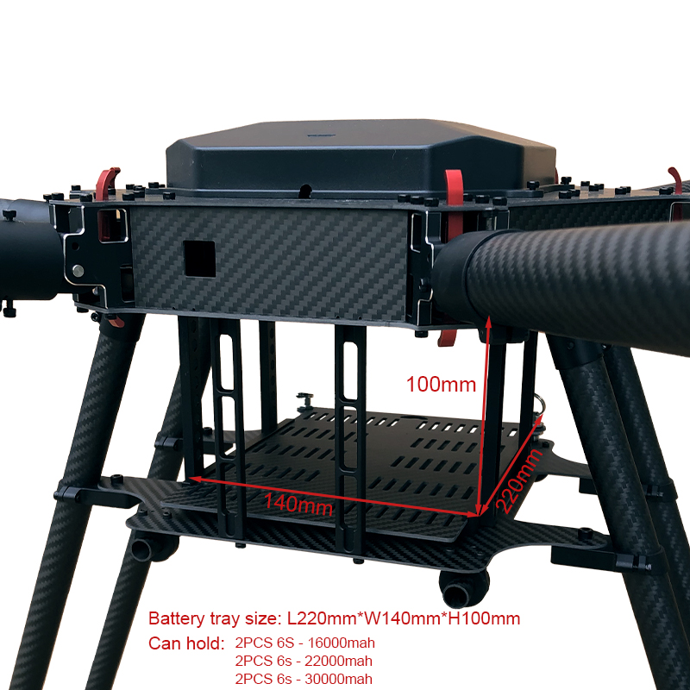
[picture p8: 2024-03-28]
wiki/01-Frame/images/frame-battery-tray.jpg

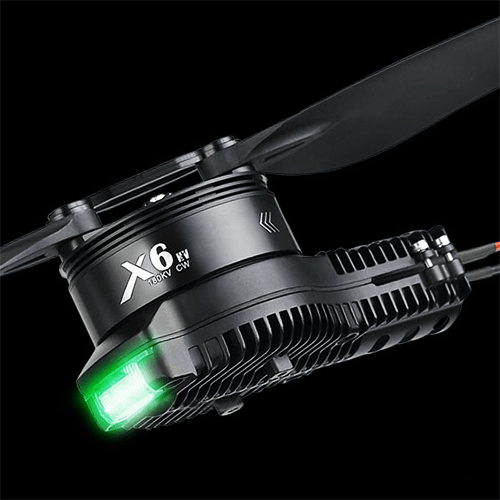
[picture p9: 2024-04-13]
wiki/06-Motors/images/motor1.png

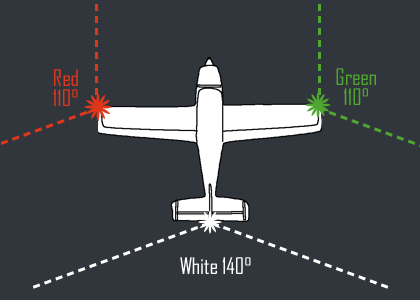
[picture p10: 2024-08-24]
wiki/14-Navigation-Lights/images/aircraft-lights-position.png

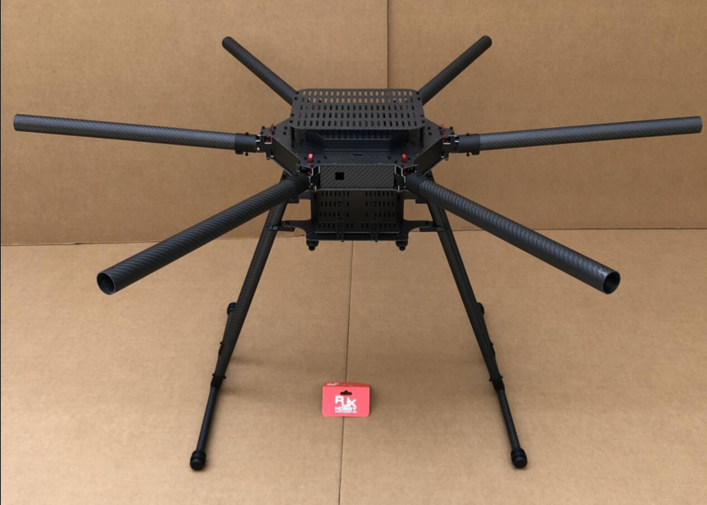
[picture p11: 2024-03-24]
wiki/01-Frame/images/frame2.png

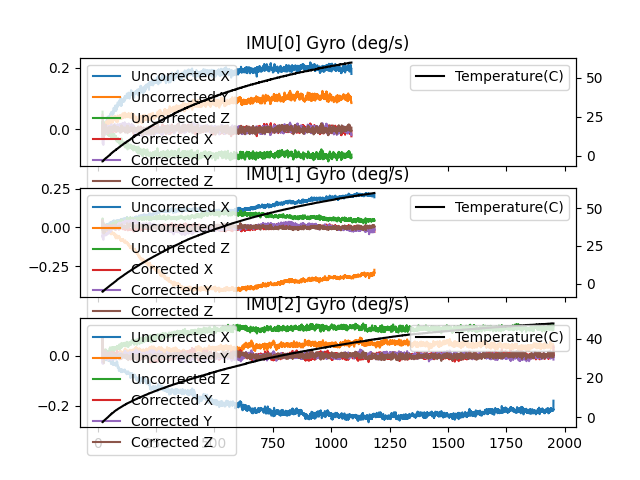
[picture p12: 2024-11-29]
ardupilot-methodic-configurator/HexacopterV2/tempcal_gyro.png

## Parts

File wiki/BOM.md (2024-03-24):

Here is the listing of all components in the Drone.

# Frame and Motors
|Component|Source|Unit Cost|Quantity|Total Cost|
|---|---|---|---|---|
|RJX1300mm 6-Axis Carbon Fiber Umbrella Folding Hexacopter Frame without motor mounts. Also request the optional top battery platform from Kenny.|[RJX Hobby](https://www.rjxhobby.com/rjx1300mm-6-axis-carbon-fiber-umbrella-folding-hexacopter-frame-with)|$1,148|1|$1,148|
|RJX 1pcs RC Drone GPS Bracket Holder Mount Suitable for 30mm/40mm/50mm Tube Agriculture Plant UAV - 30mm variant|[RJX Hobby](https://www.rjxhobby.com/rjx-1pcs-rc-drone-gps-bracket-holder-mount-suitable-for-30mm-35mm-40mm-tube-agriculture-plant-uav)|$15|2|$30|
|RJX 1PCS RC Agriculture UAV Frame AS150U Plug Fixed Seat Male Connector Mount Holder Support Base for 20mm 25mm Carbon Tube - 20mm variant|[RJX Hobby](https://www.rjxhobby.com/rjx-1pcs-rc-agriculture-uav-frame-as150u-plug-fixed-seat-male-connector-mount-holder-support-base-for-20mm-25mm-carbon-tube)|$12|1|$12|
|Hobbywing XRotor X6 Plus system - Clockwise CW Motors|[Hobbywing](https://www.hobbywingdirect.com/products/xrotor-x6-plus?variant=40960661094515)|$170|3|$510|
|Hobbywing XRotor X6 Plus system - CounterClockwise CCW Motors|[Hobbywing](https://www.hobbywingdirect.com/products/xrotor-x6-plus?variant=40960661127283)|$170|3|$510|
|100ft - 1/4 inch PET Expandable Braided Sleeving|[Amazon](https://www.amazon.com/gp/product/B074GM1PK1/ref=ox_sc_act_title_1?smid=A2N7NRZ9X3BHHN&psc=1)|$14|1|$14|
|Loctite Threadlocker Blue 242|[Amazon](https://www.amazon.com/gp/product/B000I1RSNS/ref=ox_sc_act_title_3?smid=ATVPDKIKX0DER&th=1)|$8|1|$8|

# Battery
|Component|Source|Unit Cost|Quantity|Total Cost|
|---|---|---|---|---|
|Amass AS150U Pigtails 8AWG AS150U Connector with Wire 350mm Silicon Wire AS150U Plug Male and Female Connector for RC Lipo Battery FPV Racing Drone (1 Pair)|[Amazon](https://www.amazon.com/gp/product/B0BMPQL7Z1/ref=ox_sc_act_title_2?smid=A1JGQIWP459RKC&psc=1)|$23|1|$23|
|Component|[Source](https:URL)|$XXX|1|$XXX|
|Component|[Source](https:URL)|$XXX|1|$XXX|

# Electronics
|Component|Source|Unit Cost|Quantity|Total Cost|
|---|---|---|---|---|
|Raspberry Pi 4b 8GB|[Amazon](https://www.amazon.com/gp/product/B08DJ9MLHV/)|$95|1|$95|
|Component|[Source](https:URL)|$XXX|1|$XXX|
|Component|[Source](https:URL)|$XXX|1|$XXX|
|Component|[Source](https:URL)|$XXX|1|$XXX|

# Miscellaneous
You need some additional items to 
|Component|Source|Unit Cost|Quantity|Total Cost|
|---|---|---|---|---|
|Component|[Source](https:URL)|$XXX|1|$XXX|
|Component|[Source](https:URL)|$XXX|1|$XXX|
|Component|[Source](https:URL)|$XXX|1|$XXX|

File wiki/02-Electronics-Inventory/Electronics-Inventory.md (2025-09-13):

This page contains an overview of the electronics to be installed in the Drone.
The complete list of parts bought can be foud on the [bill of materials page](../00-Bill-of-Materials/Bill-of-Materials.md) - This page contains the overall bill of materials/component list that was used to construct the drone.

# YouTube Video
- [Hexacopter Drone Build Project – Part 2 Electronics Inventory](https://www.youtube.com/watch?v=9nkmOGkzU3E)

# References 
## Kore Multi-Rotor Carrier Board
- Details about the Kore carrier board [can be found here](https://docs.spektreworks.com/carrier_board_v1_3_1/).
- You can download STL files to 3d print a case for the Kore carrier board [from here](https://www.spektreworks.com/products/multi-rotor-pixhawk21-carrier-board). We dont use this in this project, but it may be an option for yours.

## Cube Pilot
Cube pilot product documentation [can be found here](https://docs.cubepilot.org/user-guides).

## Here Flow 3d Printed Case
You can download and 3d print a case for the Here Flow [from here](https://discuss.cubepilot.org/t/hereflow-3d-printed-enclosure/1890/8). You will need 3 x 2.5x6mm socket head screws as well.

# Pictures
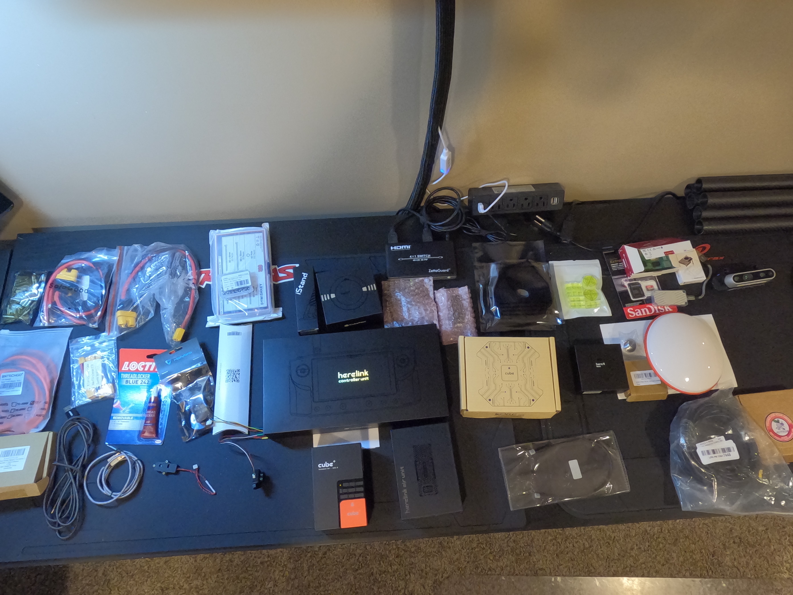
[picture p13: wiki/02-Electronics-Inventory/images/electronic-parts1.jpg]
Parts


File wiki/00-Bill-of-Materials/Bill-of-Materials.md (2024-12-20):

This page contains the overall bill of materials/component list that was used to construct the drone. Parts availability may change over time and so you may have to find alternatives as this site ages. Costs are as of 2024, and are rounded to nearest dollar. Shipping and tax is generally not included in the costs below.

# Frame
|Component|Source|Unit Cost|Quantity|Total Cost|
|---|---|---|---|---|
|RJX1300mm 6-Axis Carbon Fiber Umbrella Folding Hexacopter Frame without motor mounts. Also request the optional top battery platform from Kenny.|[RJX Hobby](https://www.rjxhobby.com/rjx1300mm-6-axis-carbon-fiber-umbrella-folding-hexacopter-frame-with)|$1,148|1|$1,148|
|RJX 1pcs RC Drone GPS Bracket Holder Mount Suitable for 30mm/40mm/50mm Tube Agriculture Plant UAV - 30mm variant|[RJX Hobby](https://www.rjxhobby.com/rjx-1pcs-rc-drone-gps-bracket-holder-mount-suitable-for-30mm-35mm-40mm-tube-agriculture-plant-uav)|$15|2|$30|
|RJX 1PCS RC Agriculture UAV Frame AS150U Plug Fixed Seat Male Connector Mount Holder Support Base for 20mm 25mm Carbon Tube - 20mm variant|[RJX Hobby](https://www.rjxhobby.com/rjx-1pcs-rc-agriculture-uav-frame-as150u-plug-fixed-seat-male-connector-mount-holder-support-base-for-20mm-25mm-carbon-tube)|$12|1|$12|
|Small Bubble Levels|[Amazon](https://www.amazon.com/gp/product/B098CWYPZC/)|$6|1|$6|
|Loctite Threadlocker Blue 242|[Amazon](https://www.amazon.com/gp/product/B000I1RSNS/)|$8|1|$8|
|Rubber Grip Tape, Ultra-Thin Strong Adhesive Anti-Slip Waterproof Heat Resistant Wear-Resistant Cushion Pad, Making Handles or Contact Surfaces Safer, with Grip and Comfort (Black, 2In x 10Ft)|[Amazon](https://www.amazon.com/gp/product/B0CLVC79BD/)|$17|1|$17|
|Cable Zip Ties,600 Packs Self-Locking Nylon CableTies Assorted Sizes 4+6+8+10+12-Inch|[Amazon](https://www.amazon.com/gp/product/B08TVMRFV8/?th=1)|$10|1|$10|
|XHF 3/4" Strong Back-Glue Self Adhesive Black Cable Zip Tie Mounts|[Amazon](https://www.amazon.com/gp/product/B08F77YVYB/)|$10|1|$10|
|25ft x 1/4 inch & 25ft x 1/2 inch PET Expandable Braided Sleeving Braided Cable Sleeve|[Amazon](https://www.amazon.com/gp/product/B07RZXSJBM/)|$10|1|$10|
|1/8 inch Cord Protector Wire Loom Tubing Cable Sleeve Split Sleeving|[Amazon](https://www.amazon.com/gp/product/B07FWFB9H6)|$14|1|$14|
|1/4 inch Cord Protector Wire Loom Tubing Cable Sleeve Split Sleeving|[Amazon](https://www.amazon.com/gp/product/B07FW86XV6/)|$14|1|$14|
|1/2 inch Cord Protector Wire Loom Tubing Cable Sleeve Split Sleeving|[Amazon](https://www.amazon.com/gp/product/B07FW3GTXB/)|$9|3|$27|
|3/4 inch Cord Protector Wire Loom Tubing Cable Sleeve Split Sleeving|[Amazon](https://www.amazon.com/gp/product/B07FW672R7/)|$12|1|$12|
|Duco ABS Plastic Sheets 1/8 Inch Thick 4" x 6"|[Amazon](https://www.amazon.com/gp/product/B0BBTDYVG9/)|$9|1|$9|
|Duco ABS Plastic Sheets 1/8 Inch Thick 6" x 6"|[Amazon](https://www.amazon.com/gp/product/B0BBTDQ73S/)|$7|1|$7|
|Duco ABS Plastic Sheet 1/8 Inch Thick 12" x 12"|[Amazon](https://www.amazon.com/gp/product/B0B79QLYBQ/)|$8|1|$8|
|20mm Aluminum Round Tube Mount Clamp w/Hardware Anodized Black|[Amazon](https://www.amazon.com/gp/product/B0CZG1L7F9/)|$10|1|$10|
|M2.5 Series Hex Brass Spacer/Standoffs + Nuts + Screws w/Storage Case for Raspberry Pi 5/4B/3B+/3B/3A+/Zero W/2W Accessories Kit|[Amazon](https://www.amazon.com/gp/product/B0756CW6Y2/)|$10|2|$20|
|PATIKIL 12pcs M3 Standoffs, M3 45+6mm Spacer Standoffs Steel Threaded Standoffs Screws Kit 3mm ID 5mm OD Metric Male Female Thread Adapters|[Amazon](https://www.amazon.com/gp/product/B0D492547D/)|$10|2|$20|
|Aluminum Male-Female Threaded Hex Standoff - 6mm Hex, 40mm Long, M3 x 0.50 mm Thread|[McMaster-Carr](https://www.mcmaster.com/98952A444/)|$3.16|16|$51|

<!--
|Component|[Source](https:URL)|$XXX|1|$XXX|
-->

# Motors
|Component|Source|Unit Cost|Quantity|Total Cost|
|---|---|---|---|---|
|Hobbywing XRotor X6 Plus system - Clockwise CW Motors|[Hobbywing](https://www.hobbywingdirect.com/products/xrotor-x6-plus?variant=40960661094515)|$170|3|$510|
|Hobbywing XRotor X6 Plus system - CounterClockwise CCW Motors|[Hobbywing](https://www.hobbywingdirect.com/products/xrotor-x6-plus?variant=40960661127283)|$170|3|$510|
|Hobbywing XRotor 2480 Propeller - Clockwise|[Hobbywing](https://www.hobbywingdirect.com/products/xrotor-2480-propeller?variant=40989998907507)|$22|3|$66|
|Hobbywing XRotor 2480 Propeller - CounterClockwise|[Hobbywing](https://www.hobbywingdirect.com/products/xrotor-2480-propeller?variant=40989998940275)|$22|3|$66|
|Hobbywing Data Link V2|[Hobbywing](https://www.hobbywingdirect.com/products/data-link-v2)|$70|1|$70|
|3pcs Male XT-60 to Female XT-30 Connector Adapter for Turnigy Drone XT30 XT60 FPV Cable 16awg|[Amazon](https://www.amazon.com/gp/product/B073Z77473/)|$10|1|$10|
|M3 x 40mm Hex Socket Head Cap Bolts|[Amazon](https://www.amazon.com/gp/product/B07VPGQ1RZ/)|$12|1|$12|
|M3 x 0.5mm Nylon Inserted Self Locking Nuts|[Amazon](https://www.amazon.com/gp/product/B07MXVZJYG/)|$7|1|$7|
|M3 x 4/5/6/8/10/12/14/16/18/20/25mm Socket Cap Screws|[Amazon](https://www.amazon.com/gp/product/B09NR8X2LV/)|$18|1|$18|

<!--
|Component|[Source](https:URL)|$XXX|1|$XXX|
|Amass 10 Pair XT90 Male Female Bullet Connectors Power Plugs|[Amazon](https://www.amazon.com/gp/product/B06ZY34369/)|$15|1|$15|
|BNTECHGO 10 Gauge Silicone Wire 10 ft red and 10 ft Black Flexible 10 AWG Stranded Tinned Copper Wire|[Amazon](https://www.amazon.com/gp/product/B01ABOPO2S/)|$17|1|$17|
-->

# Battery
|Component|Source|Unit Cost|Quantity|Total Cost|
|---|---|---|---|---|
|Tattu Plus 1.0 Compact Version 16000mAh 44.4V 15C 12S1P Lipo Smart Battery Pack With AS150U Plug|[Tattu](https://genstattu.com/tattu-plus-1-0-compact-version-16000mah-44-4v-15c-12s1p-lipo-smart-battery-pack-with-as150u-plug/)|$695|1|$695|
|Tattu Dual-Channel Smart Charger 60A/3200W For 6S-14S LiPo Tattu Smart Battery|[Tattu](https://genstattu.com/tattu-dual-channelsmart-charger-60a-3200w-for-6s-14s-lipo-tattu-smart-battery/)|$750|1|$750|
|Amass AS150U Pigtails 8AWG AS150U Connector with Wire 350mm Silicon Wire AS150U Plug Male and Female Connector for RC Lipo Battery FPV Racing Drone (1 Pair)|[Amazon](https://www.amazon.com/gp/product/B0BMPQL7Z1/)|$23|1|$23|
<!--
|Component|[Source](https:URL)|$XXX|1|$XXX|
|Component|[Source](https:URL)|$XXX|1|$XXX|
-->

# Electronics - Onboard Drone
|Component|Source|Unit Cost|Quantity|Total Cost|
|---|---|---|---|---|
|Raspberry Pi 5 8GB|[Adafruit](https://www.adafruit.com/product/5813)|$80|1|$80|
|Official Raspberry Pi 5 Active Cooler|[Adafruit](https://www.adafruit.com/product/5815)|$5|1|$5|
|Coral USB Edge TPU ML Accelerator|[Amazon](https://www.amazon.com/gp/product/B07R53D12W/)|$75|1|$75|
|Intel RealSense Depth Camera D435|[Amazon](https://www.amazon.com/gp/product/B07BLS5477/)|$303|1|$303|
|SanDisk 128GB Extreme microSDXC UHS-I Memory Card - for Raspberry Pi|[Amazon](https://www.amazon.com/gp/product/B09X7BK27V/)|$19|1|$19|
|SanDisk 64GB 2-Pack Ultra microSDXC UHS-I Memory Card (2x64GB) - for herelink controller and air unit|[Amazon](https://www.amazon.com/gp/product/B0B7NVMBPL/)|$17|1|$17|
|Herelink Antenna Upgrade Kit|[IR-Lock](https://irlock.com/products/herelink-antenna-upgrade-kit?variant=32628365000755)|$35|1|$35|
|Kore Carrier Board|[IR-Lock](https://irlock.com/products/the-cube-kore-without-cube?variant=12823641718835)|$300|1|$300|
|Herelink HDMI Cable|[IR-Lock](https://irlock.com/products/herelink-hdmi-cable?variant=41104510615603)|$10|1|$10|
|Herelink HD Video Transmission System (V1.1)|[IR-Lock](https://irlock.com/products/herelink-hd-video-transmission-system-_?variant=40682840719411)|$899|1|$899|
|Here4 Multiband RTK GNSS|[IR-Lock](https://irlock.com/products/here4-multiband-rtk-gnss?variant=41312937639987)|$225|1|$225|
|Cube Orange+ Standard Set ADS-B|[IR-Lock](https://irlock.com/products/cube-orange-standard-set?variant=40910825979955)|$350|1|$350|
|Here iStand for Here4 GPS|[IR-Lock](https://irlock.com/products/here-istand?variant=40234969432115)|$20|1|$20|
|Herelink Air Unit (V1.1) Ethernet Cable|[IR-Lock](https://irlock.com/products/herelink-air-unit-v1-1-ethernet-cable?variant=41185288880179)|$7|1|$7|
|Here Flow|[IR-Lock](https://irlock.com/products/here-flow)|$75|1|$75|
|CAN BUS Splitter|[IR-Lock](https://irlock.com/products/can-bus-splitter)|$15|3|$45|
|Cube ID - CAN Version|[IR-Lock](https://irlock.com/collections/pixhawk2/products/cube-id_can)|$69|1|$69|
|MATEKSYS PM12S-3 Power Module|[GetFPV](https://www.getfpv.com/mateksys-pm12s-3-power-module.html)|$50|1|$50|
|MakerFocus TFmini-s Micro Lidar Module|[Amazon](https://www.amazon.com/gp/product/B075V5TZRY/)|$40|1|$40|
|Strobon V2 Cree Edition - Navigation Strobe Lights - 1 white, 2 red, 2 green|[Flytron](https://store.flytron.com/collections/led-light-systems/products/strobon-v2-cree-edition-navigation-strobe-lights)|$13|5|$65|
|SwitchBlox - Small Ethernet Switch|[BotBlox](https://botblox.io/products/small-ethernet-switch)|$73|1|$73|
|SwitchBlox Cable Adapter for Ardupilot|[BotBlox](https://botblox.io/switchblox-cable-adapter-for-ardupilot/)|$15|1|$15|
|BotBlox PicoBlade to Tinned Leads, 4 way, 0.3 meters|[BotBlox](https://botblox.io/botblox-picoblade-to-tinned-leads-4-way-0-3-meters/)|$2.20|5|$11|
|BotBlox PicoBlade to RJ45 cable, 4 way, 0.3 meters|[BotBlox](https://botblox.io/botblox-picoblade-to-rj45-cable-4-way-0-3-meters/)|$3|2|$6|
|XT90 Plug Series Battery Connector 1 Female 2 Males Adapter with 10CM 10AWG Silicon Cable|[Amazon](https://www.amazon.com/gp/product/B084VK7N9D/)|$11|1|$11|
|AS150U Female to XT90 Male Connector, 8AWG Insulated Weatherproof XT90 Male Connector|[Amazon](https://www.amazon.com/gp/product/B0CBHV4S2M/)|$18|1|$18|
|12 Gauge Silicone Wire 10 ft red and 10 ft Black Flexible 12 AWG Stranded Tinned Copper Wire|[Amazon](https://www.amazon.com/gp/product/B01ABOPMEI/)|$13|1|$13|
|Holybro CAN Hub|[Holybro](https://holybro.com/products/can-hub)|$28|2|$56|
|20 Pairs Silicone Male & Female JST Connector 22 AWG|[Amazon](https://www.amazon.com/gp/aw/d/B00EZH8P9W)|$12|1|$12|
|10 Pairs 2.0mm Spade 2P Cable 8cm Lead Plug Connector Male and Female|[Amazon](https://www.amazon.com/gp/aw/d/B07YQY9V6F)|$8|1|$8|
|20 Pairs XT30 Connectors Male and Female|[Amazon](https://www.amazon.com/gp/product/B0875MBLNH/)|$12|1|$12|
|Heat Shrink Tubing Tube Sleeving Wrap Cable Wire 5 Color 8 Size|[Amazon](https://www.amazon.com/gp/product/B00OZSL8UE/)|$12|1|$12|
|Heat Shrink Tubing Kit, 3:1 Industrial Electrical Shrink Tube, Marine Grade Shrink Wrap, Adhesive Lined, 200PCS, 7 Sizes, Black|[Amazon](https://www.amazon.com/gp/product/B0BVM4FMY9/)|$10|1|$10|
|USB Type C PD Pigtail Cable Charge Bare Wire Data Transmission Extension Power Cable 6 Cores 5A|[Amazon](https://www.amazon.com/gp/product/B0C1YXM9PF/)|$12|1|$12|
|UCTRONICS 0.96 Inch OLED Module 12864 128x64 Yellow Blue SSD1306|[Amazon](https://www.amazon.com/gp/product/B072Q2X2LL/)|$7|1|$7|
|28 AWG Silicone Wire Kit Spool 25ft Each 6 Colors|[Amazon](https://www.amazon.com/gp/product/B089CWGQKW/)|$9|1|$9|
|JST GH 1.25mm Connector Kit,2/3/4/5/6/7/8/10 Pin Housing Connectors,1.25mm Pitch JST Adapter|[Amazon](https://www.amazon.com/gp/product/B0CYZCWB4X/)|$14|1|$14|
|XT90 Male to XT60 Female Connector Adapter with 12awg|[Amazon](https://www.amazon.com/gp/product/B07PGVZJNZ/)|$10|1|$10|
|XT60 Male to XT90 Female Connector Adapter with 14awg|[Amazon](https://www.amazon.com/gp/product/B07YRRK7CG/)|$9|1|$9|
|20 Pairs Gold-Plated 4MM Banana Plug Bullet|[Amazon](https://www.amazon.com/dp/B096DWRP14)|$9|1|$9|
|20 Pairs Gold-Plated 5MM Banana Plug Bullet|[Amazon](https://www.amazon.com/gp/product/B096DSBBZQ/)|$13|1|$13|
|20 Pairs Gold-Plated 6MM Banana Plug Bullet|[Amazon](https://www.amazon.com/dp/B096DN996B)|$13|1|$13|
|20 Pairs Gold-Plated 6.5MM Banana Plug Bullet|[Amazon](https://www.amazon.com/gp/product/B096DFJYYS)|$13|1|$13|
|9 PCS 1.25mm to Dupont 2.54mm Pitch Adapter Cables Wire Compatible with JST Molex PicoBlade 1.25 for Pixhawk Flight Controller RC Drone 2Pin to 8P|[Amazon](https://www.amazon.com/gp/product/B07PWZTC88/)|$9|1|$9|
|120pcs Breadboard Jumper Wires 10cm 15cm 20cm 30cm 40cm 50 cm 100cm Wire Length Optional Dupont Cable Assorted Kit Male to Female Male to Male Female to Female Multicolored Ribbon Cables|[Amazon](https://www.amazon.com/gp/product/B07GD2BWPY/)|$7|1|$7|
|RJ45 Coupler|[Amazon](https://www.amazon.com/gp/product/B072HW3WSS/)|$10|1|$10|
|Micro USB Left Angle,Micro USB Extension Cable, 90 Degree Micro-B Male to Female Extension Cable|[Amazon](https://www.amazon.com/gp/product/B07MC7YSR2/)|$6|1|$6|
|SMA Female Bulkhead Mount to SMA Male RG316 Antenna Extension Cable 2 feet 60cm 2-Pack|[Amazon](https://www.amazon.com/gp/product/B07WC5WPK5/)|$7|1|$7|
|SMA Female Bulkhead Mount to SMA Male RG316 Antenna Extension Cable 12 inch 30cm 2-Pack|[Amazon](https://www.amazon.com/gp/product/B07MJQWH8S/)|$7|1|$7|
|CubePilot - CAN Cable 15cm|[3DXR](https://www.3dxr.co.uk//electronics-c78/connectors-c107/cubepilot-can-cable-p4991/s5713)|$3|5|$15|
|CubePilot - CAN Cable 25cm|[3DXR](https://www.3dxr.co.uk//electronics-c78/connectors-c107/cubepilot-can-cable-p4991/s5714)|$3|3|$9|
|CubePilot - CAN Cable 40cm|[3DXR](https://www.3dxr.co.uk//electronics-c78/connectors-c107/cubepilot-can-cable-p4991/s5715)|$4|2|$8|
|CubePilot - CAN Cable 60cm|[3DXR](https://www.3dxr.co.uk//electronics-c78/connectors-c107/cubepilot-can-cable-p4991/s5716)|$4|2|8|
|CubePilot - CAN Cable 100cm|[3DXR](https://www.3dxr.co.uk//electronics-c78/connectors-c107/cubepilot-can-cable-p4991/s5717)|$5|2|$10|
|RFDesign - PIXHAWK 2 to RFD900/868 Telemetry Cable 300mm|[3DXR]([https:URL](https://www.3dxr.co.uk//radio-gear-c33/telemetry-c31/telemetry-cables-accessories-c465/rf-design-rfdesign-pixhawk-2-to-rfd900-868-telemetry-cable-p5415/s6560))|$6|2|$12|
|RFDesign - PIXHAWK 2 to RFD900/868 Telemetry Cable 750mm|[3DXR](https://www.3dxr.co.uk//radio-gear-c33/telemetry-c31/telemetry-cables-accessories-c465/rf-design-rfdesign-pixhawk-2-to-rfd900-868-telemetry-cable-p5415/s6884)|$8|2|$16|
|3-pin servo Extension, Male-Female JR Plug servo Extension Lead Cable, Used for RC Quadcopter Aircraft (5 Sizes) 50 cm/19.7in 5PCS|[Amazon](https://www.amazon.com/gp/product/B09MNLP1ZG/)|$7|1|$7|
|5pcs JR Y Connector Servo Extension Cable 3 Pin JR Plug Splitters 1 Male to 4 Female Servo Y Extension Connector|[Amazon](https://www.amazon.com/gp/product/B0BC5QNDTC/)|$9|1|$9|
|20Pcs Micro JST GH 4Pin 1.25mm Male to Male Connector, GH1.25 Terminal Connector Wire Cable 15cm 28AWG|[Amazon](https://www.amazon.com/gp/product/B0C2ZQHZ9T/)|$10|1|$10|
|5 Pairs JST Plug to JR Connector Male Female Cable 10cm Servo Adapter Wire for RC Plane Helicopter Car (JST to JR-10pcs)|[Amazon](https://www.amazon.com/gp/product/B0CQXB94HX/)|$7|1|$7|
|Matek AP_PERIPH CAN Node L431 Board|[Amazon](https://www.amazon.com/gp/product/B0BC16ZRCB/)|$21|2|$42|
|Lightware SF45/B LiDAR|[Amazon](https://lightwarelidar.com/shop/sf45-b-50-m/)|$450|1|$450|
|WS2812B LED Strip Light 3.3FT/1M 144LEDs/m|[Amazon](https://www.amazon.com/gp/product/B097BXQF8J/)|$10|1|$10|

# Electronics - Gimbal and Camera
|Component|Source|Unit Cost|Quantity|Total Cost|
|---|---|---|---|---|
|GREMSY T7 Gimbal|[Gremsy](https://gremsy.com/gremsy-t7-store)|$2350|1|$2350|
|DAMPING PLATE PRO 2.0|[Gremsy](https://gremsy.com/online-store/h-accessories/damping-plate-pro-20)|$265|1|$265|
|HDMI HYPER QUICK RELEASE|[Gremsy](https://gremsy.com/online-store/t-s-accessories/hdmi-hyper-quick-release)|$235|1|$235|
|mRo 6-Pin JST-GH to 6-Pin JST-GH Twisted Pair - MRC0212 - 1000mm. Used for Gimbal serial connection.|[3DR](https://store.3dr.com/mro-6-pin-jst-gh-to-6-pin-jst-gh-twisted-pair-mrc0212/)|$12|2|$24|
|4pcs 12mm Carbon Fiber Tube 12mmx10mmx330mm,6/8/10/14/16mm Available, 3K roll Wrapped Twill Matte Finish|[Amazon](https://www.amazon.com/gp/product/B09FZZ1JD8/ref=ppx_yo_dt_b_asin_title_o00_s00?ie=UTF8&psc=1)|$22|1|$22|
|AirPixel AIR Commander ENTIRE R3|[IR-Lock](https://irlock.com/products/airpixel-air-commander-entire-r3?variant=41720690409523)|$279|1|$279|
|AirPixel Wiring set EVO for Gremsy T3 S1 T7|[IR-Lock](https://irlock.com/products/airpixel-wiring-set-evo-for-gremsy-t3-s1-t7?variant=41754869104691)|$89|1|$89|
|SanDisk 128GB Ultra microSDXC UHS-I Memory Card|[Amazon](https://www.amazon.com/gp/product/B0B7NTY2S6/)|$13|1|$13|
|NICEYRIG Camera Cage for Sony Alpha A6400 A6500 with Second Lock Point|[Amazon](https://www.amazon.com/gp/product/B082LT9Z82/)|$32|1|$32|
|NICEYRIG Cable Lock Clamp for HDMI USB-C Power Cable|[Amazon](https://www.amazon.com/gp/product/B095K4DR8J)|$16|1|$16|
|Stainless Steel D Shaft D-Ring 1/4" Tripod Screw|[Amazon](https://www.amazon.com/gp/product/B00KI3J7G2/)|$7|1|$7|
|Sony Alpha a6500 Mirrorless Digital Camera w/ 2.95" LCD|Ebay|$550|1|$550|
|Sony 16-50mm f/3.5-5.6 OSS Alpha E-Mount Retractable Zoom Lens|Ebay|$200|1|$200|
|Screen Protector for Sony a6500|[Amazon](https://www.amazon.com/gp/product/B075T5BYHK/)|$7|1|$7|
|SanDisk 128GB Extreme PRO SDXC UHS-I Memory Card|[Amazon](https://www.amazon.com/gp/product/B09X7FXHVJ/)|$23|1|$23|
|Standard SD SDHC Male to SD Female Extension Memory Card Kit Soft Flat FPC Cable Extender 25cm Compatible for GPS Camera|[Amazon](https://www.amazon.com/gp/product/B01M22RI5U/)|$9|1|$9|
|HDMI 1.4 Type D Micro HDMI Male to Micro HDMI Female M/F Extension Cable 30cm|[Amazon](https://www.amazon.com/gp/product/B00S6B8TCQ/)|$7|1|$7|
|1/4oz, 0.25oz, Black, Adhesive Stick on Wheel Weights, EasyPeel Type|[Amazon](https://www.amazon.com/gp/product/B085LCFFZS/)|$8|1|$8|

<!--
|Component|[Source](https:URL)|$XXX|1|$XXX|
|Component|[Source](https:URL)|$XXX|1|$XXX|
-->

# Electronics - Ground Control Station GPS
|Component|Source|Unit Cost|Quantity|Total Cost|
|---|---|---|---|---|
|GNSS Multi-Band L1/L2/L5 Surveying Antenna - TNC (SPK6618H)|[Sparkfun](https://www.sparkfun.com/products/21801)|$125|1|$125|
|Here4 Base|[IR-Lock](https://irlock.com/products/here4-base?variant=41465686491187)|$150|1|$150|
|TNC Male to SMA Male RF Coaxial Adapter|[Amazon](https://www.amazon.com/DGZZI-2-Pack-Coaxial-Adapter-Connector/dp/B06ZZGGWBS)|$9|1|$9|
|Antenna Thread Adapter - 1/4in. to 5/8in.|[Sparkfun](https://www.sparkfun.com/products/17546)|$6|1|$6|
|SMA Male to SMA Female Bulkhead Cable 33ft RG58 Coaxial Cable 50 Ohm|[Amazon](https://www.amazon.com/SUPERBAT-Coaxial-Adapter-Enhancer-Wireless/dp/B086JJF5ZC/ref=sr_1_8)|$20|1|$20|
|Amazon Basics 50-inch Lightweight Camera Mount Tripod Stand With Bag, Black/Brown|[Amazon](https://www.amazon.com/gp/product/B00XI87KV8/)|$16|1|$16|
<!--
|Component|[Source](https:URL)|$XXX|1|$XXX|
|Component|[Source](https:URL)|$XXX|1|$XXX|
-->

# Ground Control Station Hardware
You will need a Windows based laptop to be able to run the appropriate utilities and ground control software such as Mission Planner. You'll also need a travel router which supports both 5Ghz and 2.4Ghz to be able to create a WiFi network if you want to be able to connect to the internet easily at the field.

|Component|Source|Unit Cost|Quantity|Total Cost|
|---|---|---|---|---|
|Lenovo - Legion 7i 16" Gaming Laptop WQXGA - Intel 14th Gen Core i9 with 32GB Memory - NVIDIA GeForce RTX 4070 8GB - 1TB SSD - Glacier White|[Best Buy](https://www.bestbuy.com/site/lenovo-legion-7i-16-gaming-laptop-wqxga-intel-14th-gen-core-i9-with-32gb-memory-nvidia-geforce-rtx-4070-8gb-1tb-ssd-glacier-white/657538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)|$1,849|1|$1,849|
|TP-Link Ultra-Portable Wi-Fi 6 AX1500 Travel Router TL-WR1502X|[Amazon](https://www.amazon.com/gp/product/B0D41G5N95/)|$50|1|$50|
|Power Bank 50000mAh 22.5W Fast Charging Portable Charger - Must support 12v and PD2.0|[Amazon](https://www.amazon.com/gp/product/B0BF54MTCG/)|$40|1|$40|

# Miscellaneous
You need some additional tools and items to complete the build as well such as:
- Screw drivers
- Allen wrenches
- Nut drivers
- Wire cutters/strippers
- Small pliers
- Soldering iron and solder
- Razor knife
- 3d printer
- Crimpers for various connectors
- Wire
- Power Supply

Here are links to some of the tools I bought are below. Feel free to substitute as needed, these are just many of the items I have bought:
|Component|Source|Unit Cost|Quantity|Total Cost|
|---|---|---|---|---|
|Soldering Station Digital Display Soldering Iron Station 392℉-896℉ Temperature Adjustable|[Amazon](https://www.amazon.com/gp/product/B07Z3KCVCL/)|$46|1|$46|
|900M Soldering Iron Tips|[Amazon](https://www.amazon.com/gp/product/B077V1VND5/)|$10|1|$10|
|63-37 Tin Lead Rosin Core Solder Wire for Electrical Soldering (0.8mm 100g)|[Amazon](https://www.amazon.com/gp/product/B076QF1Y85/)|$12|1|$12|
|SRA #312 Soldering Flux Pen Low-Solids, No-Clean|[Amazon](https://www.amazon.com/gp/product/B008OC0E5M/)|$10|1|$10|
|3 in 1 Automatic Self Adjusting Wire Stripper/ Cutter/ Crimper, 8 Inch Multi Pliers For Electrical Wire Stripping, Cable Cutting, Crimping Tool from 8 AWG to 30 AWG|[Amazon](https://www.amazon.com/gp/product/B08W44T2XJ/)|$28|1|$28|
|Silicone Soldering Holder- Wire Holder for Soldering|[Amazon](https://www.amazon.com/gp/product/B0CTJ33VJY)|$12|1|$12|
|iCrimp IWS-3220M Micro Connector Pin Crimping Tool 0.03-0.52mm² 32-20AWG Ratcheting Crimper for D-Sub,Open Barrel suits Molex,JST,JAE|[Amazon](https://www.amazon.com/gp/product/B078WPT5M1/)|$26|1|$26|
|Watt Meter Power Analyzer - Greatlong 200A Power Analyzer, High Precision RC with Digital LCD Screen for voltage (V) current (A) Power (W) Charge(Ah) and Energy (Wh) Measurement|[Amazon](https://www.amazon.com/gp/product/B0CC5CFT47/)|$15|1|$15|
|Machinist Ruler, 4 Pack (6, 8, 12, 14 inch), Metric Ruler, Millimeter Ruler, (1/64, 1/32, mm and .5 mm), 6 inch Ruler, Stainless Steel Ruler|[Amazon](https://www.amazon.com/gp/product/B086TWLKC1/)|$8|1|$8|
|Electronic digital calipers, inch and millimeter conversion,LCD screen displays 0-6"caliper measuring tool|[Amazon](https://www.amazon.com/gp/product/B08ZNQRB39/?th=1)|$8|1|$8|
|Liquid Electrical Tape, Clear - 4 OZ Can with Applicator Brush - Waterproof, UV-Resistant, Dielectric Sealant for Wires & Cables, Marine & Home Use|[Amazon](https://www.amazon.com/gp/product/B000BO93RG)|$17|1|$17|

<!--
|Component|[Source](https:URL)|$XXX|1|$XXX|
|Component|[Source](https:URL)|$XXX|1|$XXX|
|Component|[Source](https:URL)|$XXX|1|$XXX|
-->

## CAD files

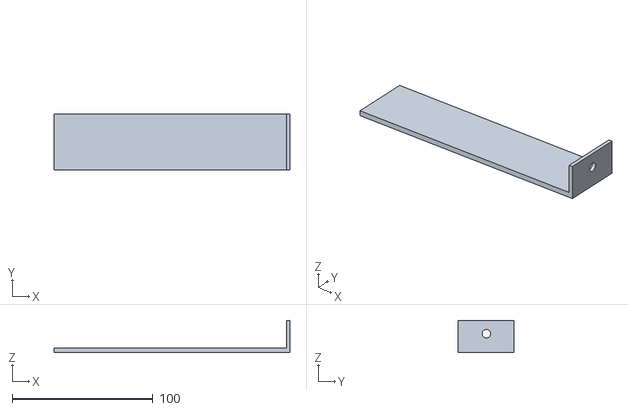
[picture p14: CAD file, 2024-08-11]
3d-print-files/antenna-l-bracket/Antenna L Bracket v2.stl
167.5 x 40.0 x 23.0

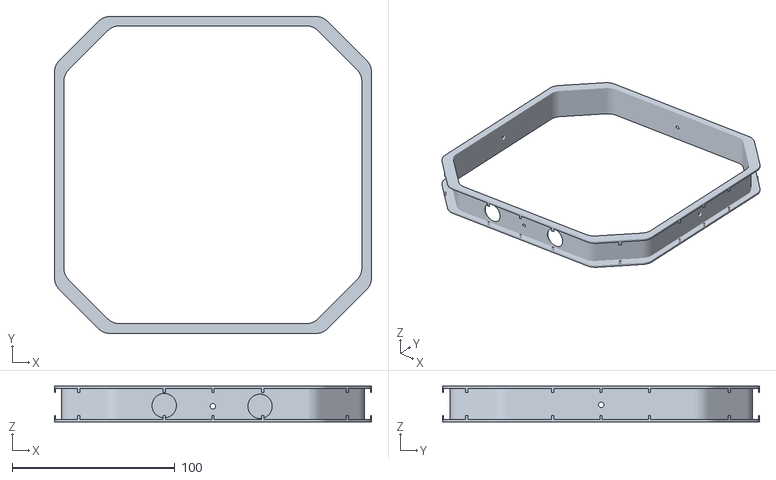
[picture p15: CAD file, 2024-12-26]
3d-print-files/drone-top-lid/Drone Top Lid LED Channel.stl
195.0 x 195.0 x 22.0

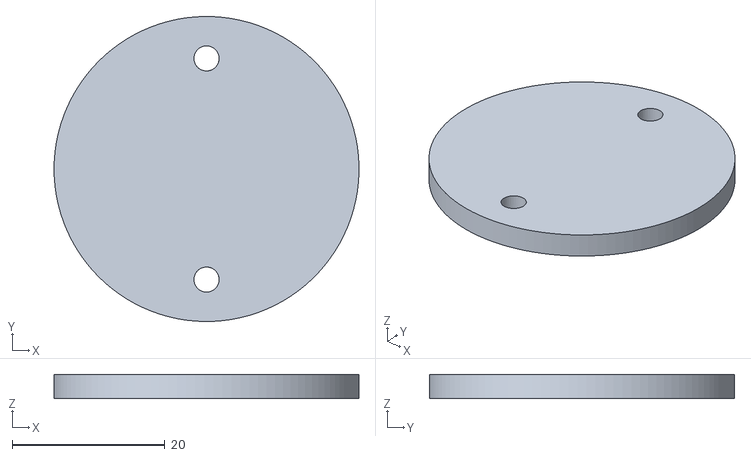
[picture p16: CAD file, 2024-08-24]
3d-print-files/motor-bottom-mounting-plate/Motor Bottom Mounting Plate v1.stl
40.0 x 40.0 x 3.18

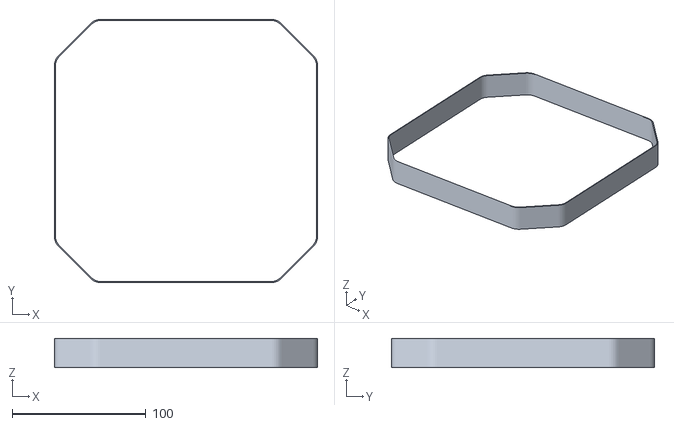
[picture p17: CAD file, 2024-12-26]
3d-print-files/drone-top-lid/Drone Top Lid LED Face.stl
196.5 x 196.5 x 22.0

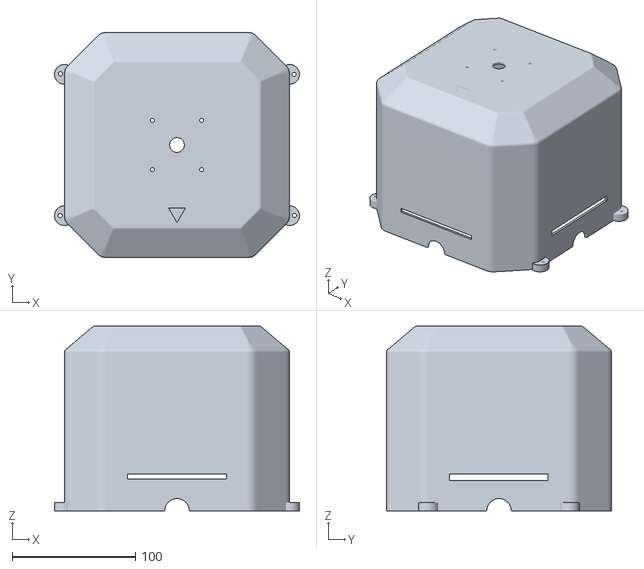
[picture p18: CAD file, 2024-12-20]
3d-print-files/drone-top-lid/Drone Top Lid.stl
198.9 x 183.0 x 150.0

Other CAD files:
3d-print-files/antenna-l-bracket/Antenna L Bracket v2.f3d
3d-print-files/drone-top-lid/Drone Top Lid LED Channel.f3d
3d-print-files/drone-top-lid/Drone Top Lid LED Face.f3d
3d-print-files/drone-top-lid/Drone Top Lid.f3d
3d-print-files/motor-bottom-mounting-plate/Motor Bottom Mounting Plate v1.f3d

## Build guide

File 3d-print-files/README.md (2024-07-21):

This folder contains subdirectories for the various 3d printed components built for the drone.
There is a folder per part containing the STL file and the Autodesk Fusion 360 archive file.

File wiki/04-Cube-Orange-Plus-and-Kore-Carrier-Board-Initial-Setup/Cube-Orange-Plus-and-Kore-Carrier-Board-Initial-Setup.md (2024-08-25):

This page contains details on the initial setup of the Cube Orange Plus and Kore Carrier Board.

# YouTube Video
- [Hexacopter Drone Build Project – Part 4 Cube Orange Plus and Kore Carrier Board Initial Setup](https://www.youtube.com/watch?v=5t4QqKYQOWc)

# Notes
- Its important to note that the auxiliary ports of the Kore carrier board map to servo ports starting at 9. So:
  - Kore Carrier Board Auxiliary Port 1 = SERVO9
  - Kore Carrier Board Auxiliary Port 2 = SERVO10
  - Kore Carrier Board Auxiliary Port 3 = SERVO11
  - Kore Carrier Board Auxiliary Port 4 = SERVO12
  - Kore Carrier Board Auxiliary Port 5 = SERVO13
  - Kore Carrier Board Auxiliary Port 6 = SERVO14
- You must supply 5v power to the auxiliary ports if you wish to power devices connected to those ports. I applied a simple 5v supply to auxiliary port 6. Applying power to one auxiliary port will power them all. It is recommended to use a BEC to supply power to these ports if you will be attaching noisy devices such as servos.

# Supporting Materials
- [ArduPilot Configuration](../ArduPilot-Config/ArduPilot-Config.md) - This page contains a consolidated list of the all of the configuration done in ArduPilot throughout the videos.

# References 
## Herelink User Guides
- User guides for the Herelink [can be found here](https://docs.cubepilot.org/user-guides/herelink/herelink-user-guides).
- User guides for the Kore Carrier Board [can be found here](https://docs.cubepilot.org/user-guides/carrier-boards/kore-carrier-board).
- Details about the Kore carrier board [can be found here](https://docs.spektreworks.com/carrier_board_v1_3_1/).
- You can download STL files to 3d print a case for the Kore carrier board [from here](https://www.spektreworks.com/products/multi-rotor-pixhawk21-carrier-board). We dont use this in this project, but it may be an option for yours.

## ArduPilot References
- [ArduPilot Tuning Process Instructions](https://ardupilot.org/copter/docs/tuning-process-instructions.html)

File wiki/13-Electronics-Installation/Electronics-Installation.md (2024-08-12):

This page contains details on the installation of the electronics into the drone frame.

# YouTube Video
- [Hexacopter Drone Build Project – Part 13 Electronics Installation](https://youtu.be/kmTBtlIYcv4)

# Notes
- Not many notes for the build, I recommend watching the video. There were lots of things to figure out and play with to get positioning right. Space in the frame ended up being tight.
- The STL and Autodesk Fusion files for the 3d printed antenna mounts are [located here](../../3d-print-files/antenna-l-bracket/).

# Supporting Materials
- [ArduPilot Configuration](../ArduPilot-Config/ArduPilot-Config.md) - This page contains a consolidated list of the all of the configuration done in ArduPilot throughout the videos.

# References 
- You can download and 3d print various cases for the OLED Display from thingiverse:
  - [0.96 OLED case](https://www.thingiverse.com/thing:5225024) - This is the one I used to attach the OLED to the drone frame. I had to sand the sides of the OLED display circuit board a little bit to get things to fit.

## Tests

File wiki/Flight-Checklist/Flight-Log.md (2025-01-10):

This page contains a sample flight log format.

# Flight Log
|Date|Time|Location of Flight|Mission Details|Flight Duration|
|---|---|---|---|---|
|TBD|TBD|TBD|TBD|TBD|

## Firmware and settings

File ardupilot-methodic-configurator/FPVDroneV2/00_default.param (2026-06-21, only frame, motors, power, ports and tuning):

ATC_ANG_LIM_TC,1
ATC_ANG_PIT_P,4.5
ATC_ANG_RLL_P,4.5
ATC_ANG_YAW_P,4.5
ATC_ANGLE_BOOST,1
ATC_RAT_PIT_D,0.0036
ATC_RAT_PIT_D_FF,0
ATC_RAT_PIT_FF,0
ATC_RAT_PIT_FLTD,20
ATC_RAT_PIT_FLTE,0
ATC_RAT_PIT_FLTT,20
ATC_RAT_PIT_I,0.135
ATC_RAT_PIT_IMAX,0.5
ATC_RAT_PIT_NEF,0
ATC_RAT_PIT_NTF,0
ATC_RAT_PIT_P,0.135
ATC_RAT_PIT_PDMX,0
ATC_RAT_PIT_SMAX,0
ATC_RAT_RLL_D,0.0036
ATC_RAT_RLL_D_FF,0
ATC_RAT_RLL_FF,0
ATC_RAT_RLL_FLTD,20
ATC_RAT_RLL_FLTE,0
ATC_RAT_RLL_FLTT,20
ATC_RAT_RLL_I,0.135
ATC_RAT_RLL_IMAX,0.5
ATC_RAT_RLL_NEF,0
ATC_RAT_RLL_NTF,0
ATC_RAT_RLL_P,0.135
ATC_RAT_RLL_PDMX,0
ATC_RAT_RLL_SMAX,0
ATC_RAT_YAW_D,0
ATC_RAT_YAW_D_FF,0
ATC_RAT_YAW_FF,0
ATC_RAT_YAW_FLTD,20
ATC_RAT_YAW_FLTE,2.5
ATC_RAT_YAW_FLTT,20
ATC_RAT_YAW_I,0.018
ATC_RAT_YAW_IMAX,0.5
ATC_RAT_YAW_NEF,0
ATC_RAT_YAW_NTF,0
ATC_RAT_YAW_P,0.18
ATC_RAT_YAW_PDMX,0
ATC_RAT_YAW_SMAX,0
ATC_RATE_FF_ENAB,1
ATC_RATE_P_MAX,0
ATC_RATE_R_MAX,0
ATC_RATE_Y_MAX,0
BATT_AMP_OFFSET,0
BATT_AMP_PERVLT,40.200001
BATT_ARM_MAH,0
BATT_ARM_VOLT,0
BATT_CAPACITY,3300
BATT_CRT_MAH,0
BATT_CRT_VOLT,0
BATT_CURR_PIN,11
BATT_FS_CRT_ACT,0
BATT_FS_LOW_ACT,0
BATT_FS_VOLTSRC,0
BATT_LOW_MAH,0
BATT_LOW_TIMER,10
BATT_LOW_VOLT,10.5
BATT_MONITOR,4
BATT_OPTIONS,0
BATT_SERIAL_NUM,-1
BATT_VLT_OFFSET,0
BATT_VOLT_MULT,21.120001
BATT_VOLT_PIN,10
BATT2_MONITOR,0
BATT3_MONITOR,0
BATT4_MONITOR,0
BATT5_MONITOR,0
BATT6_MONITOR,0
BATT7_MONITOR,0
BATT8_MONITOR,0
BATT9_MONITOR,0
FLTMODE_CH,5
FLTMODE_GCSBLOCK,0
FLTMODE1,0
FLTMODE2,0
FLTMODE3,0
FLTMODE4,0
FLTMODE5,0
FLTMODE6,0
FRAME_CLASS,0
FRAME_TYPE,1
INS_GYRO_FILTER,20
INS_HNTCH_ATT,40
INS_HNTCH_BW,40
INS_HNTCH_ENABLE,0
INS_HNTCH_FM_RAT,1
INS_HNTCH_FREQ,80
INS_HNTCH_HMNCS,1
INS_HNTCH_MODE,1
INS_HNTCH_OPTS,0
INS_HNTCH_REF,0
MOT_BAT_CURR_MAX,0
MOT_BAT_CURR_TC,5
MOT_BAT_IDX,0
MOT_BAT_VOLT_MAX,0
MOT_BAT_VOLT_MIN,0
MOT_BOOST_SCALE,0
MOT_HOVER_LEARN,2
MOT_OPTIONS,0
MOT_PWM_MAX,2000
MOT_PWM_MIN,1000
MOT_PWM_TYPE,0
MOT_SAFE_DISARM,0
MOT_SAFE_TIME,1
MOT_SLEW_DN_TIME,0
MOT_SLEW_UP_TIME,0
MOT_SPIN_ARM,0.1
MOT_SPIN_MAX,0.95
MOT_SPIN_MIN,0.15
MOT_SPOOL_TIM_DN,0
MOT_SPOOL_TIME,0.5
MOT_THST_EXPO,0.65
MOT_THST_HOVER,0.35
MOT_YAW_HEADROOM,200
SERIAL0_BAUD,115
SERIAL0_PROTOCOL,2
SERIAL1_BAUD,57
SERIAL1_OPTIONS,0
SERIAL1_PROTOCOL,2
SERIAL2_BAUD,57
SERIAL2_OPTIONS,0
SERIAL2_PROTOCOL,42
SERIAL3_BAUD,230
SERIAL3_OPTIONS,0
SERIAL3_PROTOCOL,5
SERIAL4_BAUD,230
SERIAL4_OPTIONS,0
SERIAL4_PROTOCOL,2
SERIAL5_BAUD,57
SERIAL5_OPTIONS,0
SERIAL5_PROTOCOL,-1
SERIAL6_BAUD,57
SERIAL6_OPTIONS,0
SERIAL6_PROTOCOL,23
SERIAL7_BAUD,57
SERIAL7_OPTIONS,0
SERIAL7_PROTOCOL,16
SERIAL8_BAUD,115
SERIAL8_OPTIONS,0
SERIAL8_PROTOCOL,2
SERVO1_FUNCTION,0
SERVO1_MAX,2000
SERVO1_MIN,1000
SERVO1_REVERSED,0
SERVO1_TRIM,1000
SERVO2_FUNCTION,0
SERVO2_MAX,2000
SERVO2_MIN,1000
SERVO2_REVERSED,0
SERVO2_TRIM,1000
SERVO3_FUNCTION,0
SERVO3_MAX,2000
SERVO3_MIN,1000
SERVO3_REVERSED,0
SERVO3_TRIM,1000
SERVO4_FUNCTION,0
SERVO4_MAX,2000
SERVO4_MIN,1000
SERVO4_REVERSED,0
SERVO4_TRIM,1000
SERVO5_FUNCTION,0
SERVO5_MAX,1900
SERVO5_MIN,1100
SERVO5_REVERSED,0
SERVO5_TRIM,1500
SERVO6_FUNCTION,0
SERVO6_MAX,1900
SERVO6_MIN,1100
SERVO6_REVERSED,0
SERVO6_TRIM,1500
SERVO7_FUNCTION,0
SERVO7_MAX,1900
SERVO7_MIN,1100
SERVO7_REVERSED,0
SERVO7_TRIM,1500
SERVO8_FUNCTION,0
SERVO8_MAX,1900
SERVO8_MIN,1100
SERVO8_REVERSED,0
SERVO8_TRIM,1500
SERVO9_FUNCTION,0
SERVO9_MAX,1900
SERVO9_MIN,1100
SERVO9_REVERSED,0
SERVO9_TRIM,1500

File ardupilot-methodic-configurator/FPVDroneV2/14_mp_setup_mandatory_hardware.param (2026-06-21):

AHRS_TRIM_X,-0.026791
AHRS_TRIM_Y,-0.01597
ATC_ACCEL_P_MAX,328671.46875
ATC_ACCEL_R_MAX,513770.78125
ATC_ACCEL_Y_MAX,387010.96875
ATC_RAT_PIT_FLTD,50.5  # INS_GYRO_FILTER / 2
ATC_RAT_PIT_FLTT,50.5  # INS_GYRO_FILTER / 2
ATC_RAT_RLL_FLTD,50.5  # INS_GYRO_FILTER / 2
ATC_RAT_RLL_FLTT,50.5  # INS_GYRO_FILTER / 2
ATC_RAT_YAW_FLTE,1.629012
ATC_RAT_YAW_FLTT,50.5  # INS_GYRO_FILTER / 2
COMPASS_CAL_FIT,16
COMPASS_DEC,0
COMPASS_DIA_X,1
COMPASS_DIA_Y,1
COMPASS_DIA_Z,1
COMPASS_EXTERNAL,1
COMPASS_ODI_X,0
COMPASS_ODI_Y,0
COMPASS_ODI_Z,0
COMPASS_OFS_X,279.429504
COMPASS_OFS_Y,30.231573
COMPASS_OFS_Z,-10.140164
COMPASS_ORIENT,2
COMPASS_PRIO1_ID,855305
COMPASS_PRIO2_ID,855297
COMPASS_SCALE,1.024439
COMPASS_USE,1  # Use the external herelink compass.
COMPASS_USE2,0  # Disable the internal compass, it seems to be much less accurate.
FENCE_ACTION,4  # 4 = Brake or Land. Set to 0 for report only.
FENCE_ALT_MAX,30  # Maximum altitude allowed before geofence triggers. Value is in meters. I set to 30 when initially testing drone.
FENCE_ALT_MIN,-10  # Minimum altitude allowed before geofence triggers. Value is in meters.
FENCE_AUTOENABLE,0  # Auto-enable of fences. Set to Disabled.
FENCE_ENABLE,1  # Allows you to enable (1) or disable (0) the fence functionality.
FENCE_MARGIN,3  # Distance that autopilot's should maintain from the fence to avoid a breach. Value is in meters.
FENCE_RADIUS,100  # Circle fence radius which when breached will cause an RTL. Value is in meters.
FENCE_TYPE,7  # Bitmask. Set to Max Altitude, Circle Centered on Home, and Inclusion/Exclusion Circles+Polygons
FLTMODE_CH,6  # RC Channel to use for flight mode control. Default is 5.
FLTMODE1,5  # Flight mode when pwm of Flightmode channel(FLTMODE_CH) is <= 1230. Set to Loiter.
FLTMODE2,2  # Flight mode when pwm of Flightmode channel(FLTMODE_CH) is >1230, <= 1360. Set to AltHold.
FLTMODE3,0  # Flight mode when pwm of Flightmode channel(FLTMODE_CH) is >1360, <= 1490. Set to Auto (For running missions).
FLTMODE4,15  # Flight mode when pwm of Flightmode channel(FLTMODE_CH) is >1490, <= 1620. Set to Autotune
FLTMODE5,6  # Flight mode when pwm of Flightmode channel(FLTMODE_CH) is >1620, <= 1749. Set to RTL.
FLTMODE6,9  # Flight mode when pwm of Flightmode channel(FLTMODE_CH) is >=1750. Set to Land.
FRAME_CLASS,1  # Quadcopter
FRAME_TYPE,1  # X type
INS_ACC2OFFS_X,-0.060999
INS_ACC2OFFS_Y,0.051721
INS_ACC2OFFS_Z,-0.112982
INS_ACC2SCAL_X,0.995196  # Copied from the connected flight controller
INS_ACC2SCAL_Y,0.993343  # Copied from the connected flight controller
INS_ACC2SCAL_Z,0.987246  # Copied from the connected flight controller
INS_ACCOFFS_X,0.060698
INS_ACCOFFS_Y,0.028126
INS_ACCOFFS_Z,0.14836
INS_ACCSCAL_X,0.993521
INS_ACCSCAL_Y,0.994283
INS_ACCSCAL_Z,0.988497
INS_GYR2OFFS_X,0.00262
INS_GYR2OFFS_Y,0.001052
INS_GYR2OFFS_Z,-0.001188
INS_GYRO_FILTER,101
INS_GYROFFS_X,-0.001298
INS_GYROFFS_Y,-0.000458
INS_GYROFFS_Z,0.001143
MOT_BAT_VOLT_MAX,25.200001  # Battery voltage compensation maximum voltage. Set to 4.2 * cell count.
MOT_BAT_VOLT_MIN,19.799999  # Battery voltage minimum compensation voltage. Set to 3.3 * cell count.
MOT_SPIN_ARM,0.03
MOT_SPIN_MAX,0.95
MOT_SPIN_MIN,0.055
MOT_THST_EXPO,0.65
MOT_THST_HOVER,0.14406
RC1_MAX,2011
RC1_MIN,988
RC1_TRIM,1500
RC10_MAX,2000
RC10_MIN,999
RC10_OPTION,31
RC10_TRIM,999
RC11_MAX,2000
RC11_MIN,999
RC11_OPTION,30
RC11_TRIM,999
RC12_MAX,2000
RC12_MIN,999
RC12_TRIM,999
RC13_TRIM,1500
RC14_MAX,2000
RC14_MIN,999
RC14_TRIM,2000
RC15_MAX,2011
RC15_MIN,2001
RC15_TRIM,2011
RC16_TRIM,1500
RC2_MAX,2011
RC2_MIN,988
RC2_REVERSED,0
RC2_TRIM,1500
RC3_MAX,2011
RC3_MIN,988
RC3_TRIM,1500
RC4_MAX,2008
RC4_MIN,988
RC4_TRIM,1499
RC5_MAX,2000
RC5_MIN,999
RC5_TRIM,2000
RC6_MAX,2000
RC6_MIN,999
RC6_TRIM,999
RC7_MAX,2000
RC7_MIN,999
RC7_OPTION,11
RC7_TRIM,2000
RC8_MAX,2000
RC8_MIN,999
RC8_OPTION,300
RC8_TRIM,999
RC9_MAX,2000
RC9_MIN,999
RC9_OPTION,171
RC9_TRIM,999
RCMAP_PITCH,3
RCMAP_ROLL,4
RCMAP_THROTTLE,2
RCMAP_YAW,1
SERVO1_FUNCTION,34  # Left Motor
SERVO2_FUNCTION,35
SERVO3_FUNCTION,36  # Right Motor
SERVO4_FUNCTION,33

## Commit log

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2024-07-05 Fixed signal handler method
    [sample01_simple_mavlink_test.py, sample02_command_examples.py]
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2024-07-21 Electronics installation folder stubbed out.
    [Battery Tray Plate.f3d, Battery Tray Plate.stl]
2024-08-10 Started files for methodic configurator
    [00_default.param, 02_imu_temperature_calibration_setup.param, 03_imu_temperature_calibration_results.param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]
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2024-08-14 Updates to methodic config
    [00_default.param, 02_imu_temperature_calibration_setup.param, 03_imu_temperature_calibration_results.param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]
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2024-08-20 Updates after quick tune performed
    [00_default.param, 23_quick_tune_results.param]
2024-08-24 Tuning Updates. Started nav lights page too
    [24_inflight_magnetometer_fit_setup.param, 25_inflight_magnetometer_fit_results.param, 27_quick_tune_results.param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]
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2024-10-16 Updates from methodic configurator
    [00_default.param, 12_mp_setup_mandatory_hardware.param]
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2024-10-22 Added board boot delay.
    [13_general_configuration.param]
2024-10-23 doc updates and gps auto switch change
    [10_gnss.param]
2024-10-25 Updates to wiki and methodic config
    [00_default.param, 12_mp_setup_mandatory_hardware.param]
2024-10-26 GPS updates, reorienting.Duel GPS for yaw updates and herelink telemetry baudrate change.
    [06_telemetry.param, 10_gnss.param, 12_mp_setup_mandatory_hardware.param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]
2024-10-26 Did temp calibration and more logging and notch filter setting updates.
    [00_default.param, 02_imu_temperature_calibration_setup.param, 03_imu_temperature_calibration_results.param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]
2024-10-27 Further notch filter tuning.
    [10_gnss.param, 13_general_configuration.param, 14_logging.param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]
2024-10-27 Updated notch tuning params
    [18_notch_filter_setup.param, 19_notch_filter_results.param]
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2024-10-27 Updates made by configurator.
    [18_notch_filter_setup.param]
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2024-10-27 Magfit and telem updates
    [06_telemetry.param, 25_inflight_magnetometer_fit_results.param, 27_quick_tune_results.param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]
2024-10-27 After step 27 quick tune.
    [27_quick_tune_results.param]
2024-10-27 Updates for loiter rates and ATC_INPUT_TC
    [13_general_configuration.param, 16_pid_adjustment.param, 20_throttle_controller.param]
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2024-11-13 Updated Methodic configurator to 0.9.12
    [08_batt1.param, 53_everyday_use.param]
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2024-11-28 Updates after temp calibration, gimbal speed update, and notch filter updates
    [00_default.param, 02_imu_temperature_calibration_setup.param, 03_imu_temperature_calibration_results.param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]
2024-11-29 Wiki updates. Temp calibration updates.
    [02_imu_temperature_calibration_setup.param, 03_imu_temperature_calibration_results.param, 12_mp_setup_mandatory_hardware.param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]
2024-11-30 Notch updates. Quiktune performed. Wiki updates.
    [12_mp_setup_mandatory_hardware.param, 19_notch_filter_results.param, 23_quick_tune_results.param]
2024-12-08 Adding initial copy of heacopter to x500 to start x500 methodic config.
    [00_default.param, 02_imu_temperature_calibration_setup.param, 03_imu_temperature_calibration_results.param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]
2024-12-08 Initial quadcopter tune prior to notch filter tuning.
    [00_default.param, 04_board_orientation.param, 05_remote_controller.param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]
2024-12-14 Methodic configurator and wiki updates
    [00_default.param, 05_remote_controller.param, 06_telemetry.param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]
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2024-12-20 Updates for cube orange conversion on quad. Wiki updates too.
    [00_default.param, 08_batt1.param, 13_general_configuration.param]
2024-12-20 Quad tuning through quiktune setup
    [00_default.param, 03_imu_temperature_calibration_results.param, 05_remote_controller.param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]
2024-12-26 Scanning LED doc updates and 3d print files. X500 Quiktune results.
    [23_quick_tune_results.param, Drone Top Lid LED Channel.f3d, Drone Top Lid LED Channel.stl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]
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2024-12-27 Added option to be able to turn on/ff proximity sensor.
    [05_remote_controller.param, 13_general_configuration.param]
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2025-01-06 Script updates for gimbal. Methodic config updates. Proximity sensor updates.
    [00_default.param, 13_general_configuration.param, 29_evaluate_the_aircraft_tune_ff_enable.param]
2025-01-10 Updates for X500 Serial port connection to flight controller.
    [13_general_configuration.param]
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2025-03-01 Reverting GPS to dronecan, no longer using moving baseline
    [10_gnss.param, 12_mp_setup_mandatory_hardware.param]
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2025-03-17 Update methodic config to 1.2.2
    [04_board_orientation.param, 05_remote_controller.param, 08_batt1.param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]
2025-03-25 Updated methodic config and enabled adsb on x500
    [04_board_orientation.param, 05_remote_controller.param, 08_batt1.param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]
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2025-04-27 Magit on x500 and notch updates on hex
    [08_batt1.param, 12_mp_setup_mandatory_hardware.param, 13_general_configuration.param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]
2025-04-30 quiktune 2nd time run
    [27_quick_tune_results.param, autobackup_02.param]
2025-04-30 Ran quikctune on hex
    [23_quick_tune_results.param, autobackup_05.param]
2025-05-26 Did magfot on hex, and ready for autotune on quad
    [25_inflight_magnetometer_fit_results.param, 27_quick_tune_results.param, 30_autotune_roll_setup.param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]
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2025-06-29 Finished step 39 for x500 roll and pitch autotuning
    [39_autotune_roll_pitch_retune_results.param]
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
